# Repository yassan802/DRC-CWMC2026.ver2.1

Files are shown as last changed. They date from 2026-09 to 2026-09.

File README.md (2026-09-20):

ESP32を搭載しており、Bluetoothでの通信が可能な中央制御基板。他の基板と通信する用とロボマス等と通信する用の２つのCAN系統がある。外部からの信号で動かせるMD基板用の端子もある。基板に挿した状態だとesp32にファームウェアを書き込めないことやLCDのコントラスト調整ができなかったりといくつかの欠陥を抱えているのですでにあるものを見ながらパターンカット、違法建築を行うことを推奨する。  
そのほかの欠点としてはピンヘッダを用いてESP32とLCDを付けることを想定しているので分厚くなることがある。
スクリーンショット 2026-09-20 113341

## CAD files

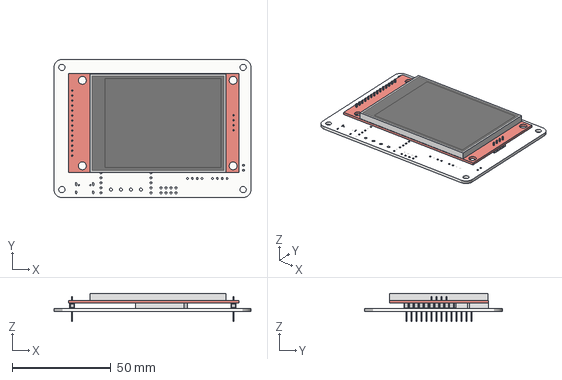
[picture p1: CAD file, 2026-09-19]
DRC-CWMC2026.ver2.1.step
100.0 x 70.0 x 14.2 mm
PCB

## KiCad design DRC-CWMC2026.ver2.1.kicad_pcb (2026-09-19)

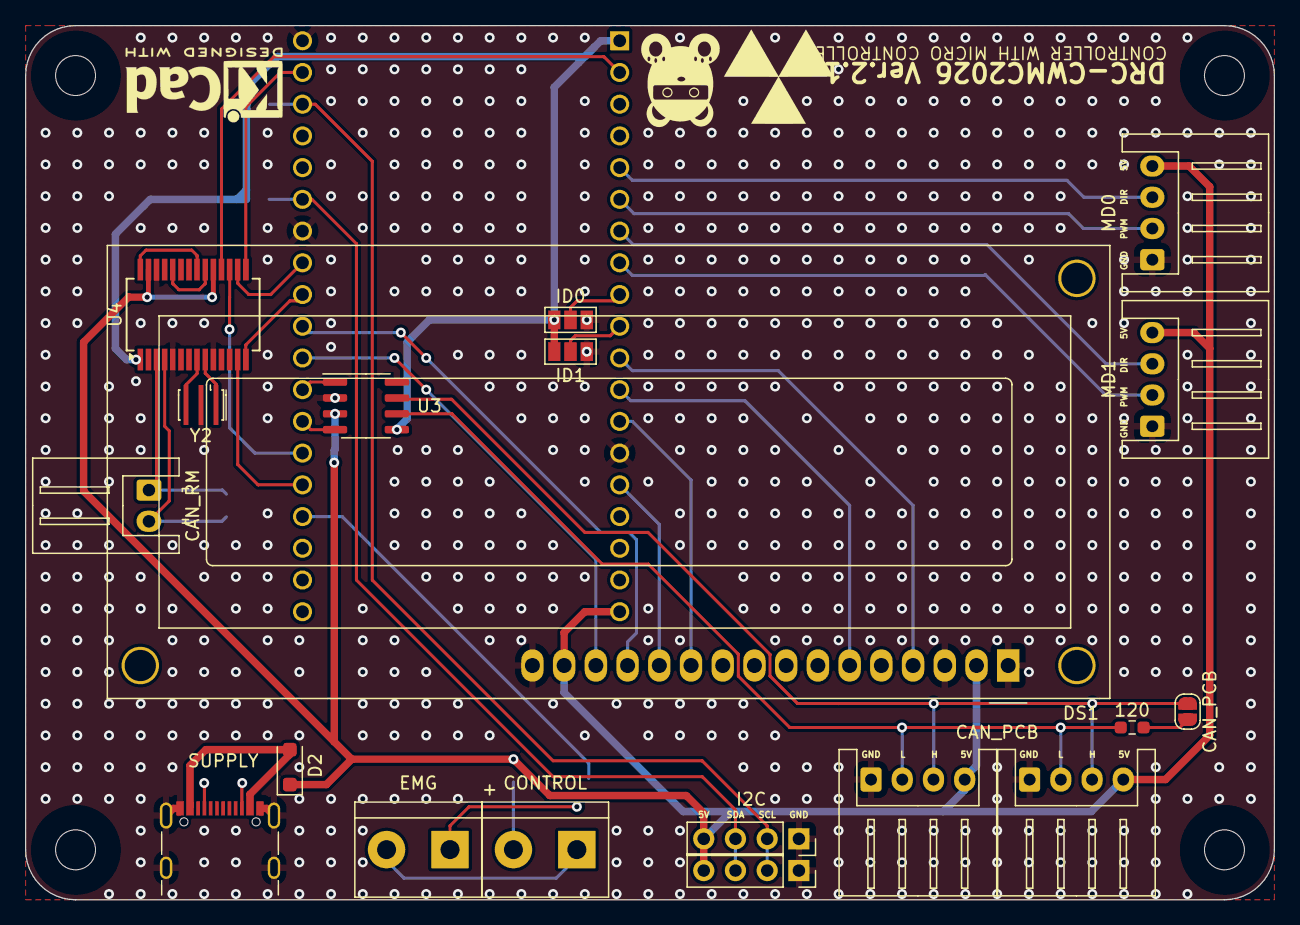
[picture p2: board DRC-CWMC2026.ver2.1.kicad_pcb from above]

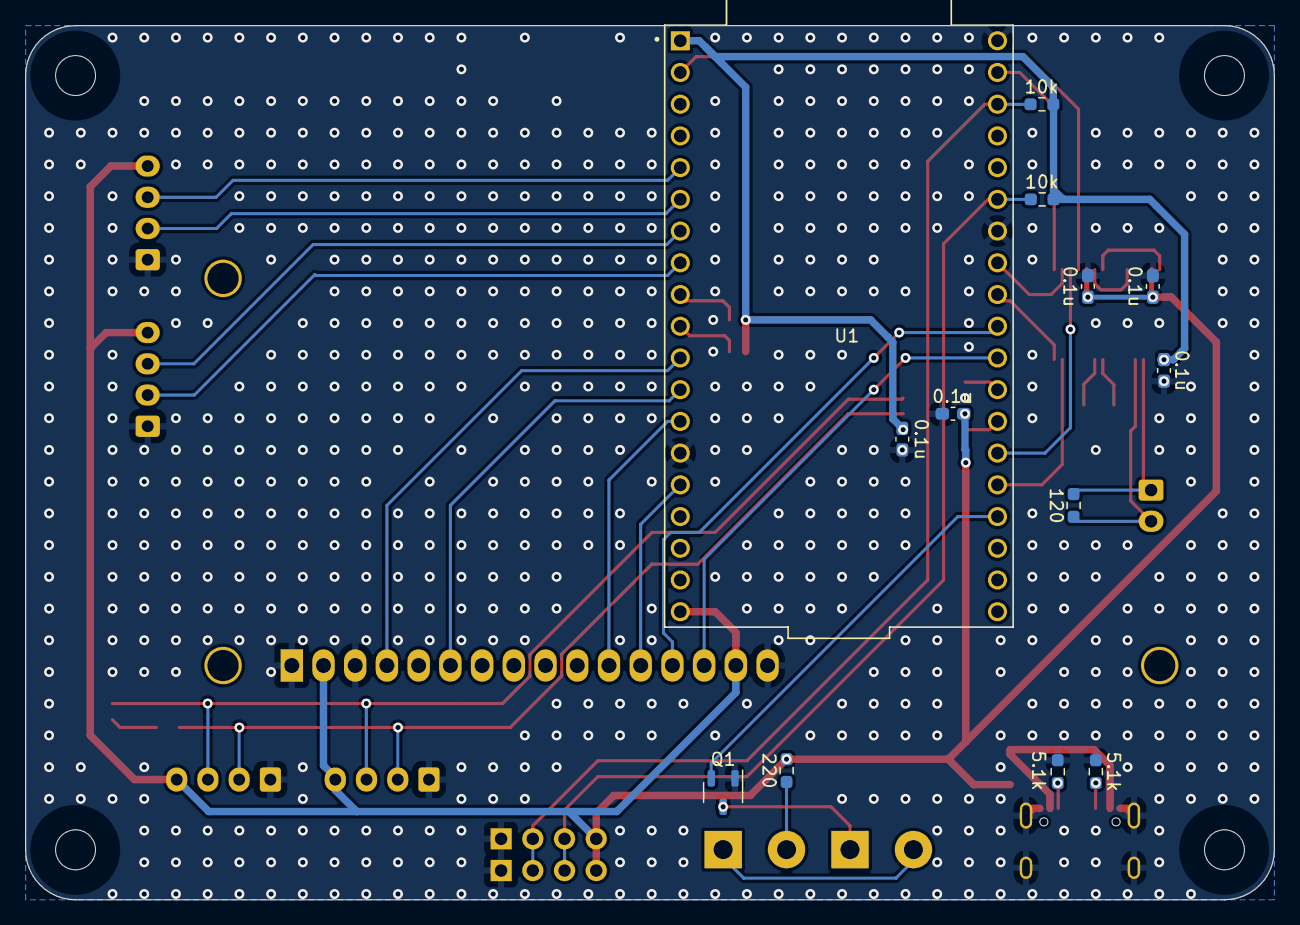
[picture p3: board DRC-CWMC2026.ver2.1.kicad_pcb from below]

Board: 2 copper layers, 100.0 x 70.0 mm, 32 parts (13 on the bottom side), 41 nets.

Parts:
0.1u, 0.1u#2, 0.1u#5: 0.1μ; C_0603_1608Metric_Pad1.08x0.95mm_HandSolder
0.1u#3, 0.1u#4: 0.1u; C_0603_1608Metric_Pad1.08x0.95mm_HandSolder
5.1k, 5.1k#2: 5.1k; R_0603_1608Metric_Pad0.98x0.95mm_HandSolder
10k, 10k#2: 10k; R_0603_1608Metric_Pad0.98x0.95mm_HandSolder
120, 120#2: 120; R_0603_1608Metric_Pad0.98x0.95mm_HandSolder
220: 220; R_0603_1608Metric_Pad0.98x0.95mm_HandSolder
CAN_PCB: CAN_RM; SolderJumper-2_P1.3mm_Open_RoundedPad1.0x1.5mm
CAN_RM: Conn_01x02_Pin; JST_XH_S2B-XH-A_1x02_P2.50mm_Horizontal
D2: ss2040; D_SOD-123F
DS1: WC1602A
J2, J3: CAN_PCB; JST_XH_S4B-XH-A_1x04_P2.50mm_Horizontal
J4: SUPPLY; USB_C_Receptacle_GCT_USB4105-xx-A_16P_TopMnt_Horizontal
J5, J6: I2C; PinSocket_1x04_P2.54mm_Vertical
J7: CONTROL; TerminalBlock_bornier-2_P5.08mm
J8: EMG; TerminalBlock_bornier-2_P5.08mm
JP1: ID0; SolderJumper-3_P1.3mm_Open_Pad1.0x1.5mm_NumberLabels
JP2: ID1; SolderJumper-3_P1.3mm_Open_Pad1.0x1.5mm_NumberLabels
MD0, MD1: MD; JST_XH_S4B-XH-A_1x04_P2.50mm_Horizontal
Q1: DTC143Z; SOT-23-3
U1: ESP32-DEVKITC; MODULE_ESP32-DEVKITC
U3: MCP2562-H-SN; SOIC-8_3.9x4.9mm_P1.27mm
U4: MCP25625-x-SS; SSOP-28_5.3x10.2mm_P0.65mm
Y2: 16MHz; Resonator_SMD_Murata_CSTxExxV-3Pin_3.0x1.1mm_HandSoldering

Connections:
+3.3V: 0.1u.1, 0.1u#3.2, 10k.1, 10k#2.1, JP1.3 (B), JP2.3 (B), U1.1 (3V3), U3.5 (Vio), U4.1 (VIO)
+5V: 0.1u#2.1, 0.1u#4.2, 0.1u#5.1, 220.1, D2.1 (K), DS1.2 (VDD), DS1.15 (LED(+)), J2.4, J3.4, J5.4, J6.4, MD0.4, MD1.4, U1.19 (EXT_5V), U3.3 (VDD), U4.19 (VDD), U4.27 (VDDA)
CAN_RX: U1.26 (IO4), U3.4 (RXD)
CAN_TX: U1.27 (IO16), U3.1 (TXD)
CONTROL: Q1.2 (B), U1.23 (IO15)
CS_CAN: U1.25 (IO0), U4.17 (~CS)
DIR1: MD0.3, U1.5 (IO34)
DIR2: MD1.3, U1.7 (IO32)
GND: 0.1u.2, 0.1u#2.2, 0.1u#3.1, 0.1u#4.1, 0.1u#5.2, 5.1k.1, 5.1k#2.1, DS1.1 (VSS), DS1.3 (VO), DS1.16 (LED(-)), J2.1, J3.1, J4.A1 (GND), J4.A12 (GND), J4.B1 (GND), J4.B12 (GND), J4.S1 (SHIELD), J5.1, J6.1, JP1.1 (A), JP2.1 (A), MD0.1, MD1.1, Q1.1 (E), U1.14 (GND1), U1.32 (GND2), U1.38 (GND3), U3.2 (VSS), U3.8 (STBY), U4.5 (STBY), U4.10 (GND), U4.26 (VSS), Y2.2
LCD1_D4: DS1.11 (D4), U1.13 (IO12)
LCD1_D5: DS1.12 (D5), U1.15 (IO13)
LCD1_D6: DS1.13 (D6), U1.29 (IO5)
LCD1_D7: DS1.14 (D7), U1.28 (IO17)
LCD_E: DS1.6 (E), U1.12 (IO14)
LCD_RS: DS1.4 (RS), U1.11 (IO27)
MISO: U1.31 (IO19), U4.16 (SO)
MOSI: U1.37 (IO23), U4.15 (SI)
unnamed: D2.2 (A), J4.A4 (VBUS), J4.A9 (VBUS), J4.B4 (VBUS), J4.B9 (VBUS)
unnamed: 5.1k.2, J4.A5 (CC1)
unnamed: 5.1k#2.2, J4.B5 (CC2)
unnamed: J7.1, J8.2
unnamed: 220.2, J7.2
unnamed: J8.1, Q1.3 (C)
unnamed: JP1.2 (C), U1.9 (IO25)
unnamed: JP2.2 (C), U1.10 (IO26)
unnamed: 120.1, CAN_PCB.1 (A)
unnamed: U4.9 (OSC1), Y2.1
unnamed: U4.8 (OSC2), Y2.3
unnamed: U4.21 (RxCAN), U4.28 (RXD)
unnamed: U4.20 (TxCAN), U4.24 (TXD)
PCBCAN_H: CAN_PCB.2 (B), J2.3, J3.3, U3.7 (CANH)
PCBCAN_L: 120.2, J2.2, J3.2, U3.6 (CANL)
PCB_INT: U1.24 (IO2), U4.13 (~INT)
PWM1: MD0.2, U1.6 (IO35)
PWM2: MD1.2, U1.8 (IO33)
RESET: U1.2 (EN), U4.18 (~RESET)
RMCAN_H: 120#2.2, CAN_RM.2, U4.4 (CANH)
RMCAN_L: 120#2.1, CAN_RM.1, U4.3 (CANL)
SCK: U1.30 (IO18), U4.14 (SCK)
SCL: 10k.2, J5.2, J6.2, U1.36 (IO22)
SDA: 10k#2.2, J5.3, J6.3, U1.33 (IO21)

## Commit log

2026-09-20 Update README with defect notes for ESP32 board
    Added notes about firmware writing issues and LCD contrast adjustment defects.
2026-09-20 Update README to clarify board description
2026-09-20 Update README with design flaws and additional details
    Added additional details about the design flaws and potential issues with the ESP32 board.
